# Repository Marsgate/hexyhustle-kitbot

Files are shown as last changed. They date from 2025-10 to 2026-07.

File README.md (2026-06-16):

# Hexy Hustle Kit Bot
This repository contains the CAD, code, and assembly instructions necessary to build a Hexy Hustle Kit Bot.

## Printing
Printable STLs have been provided for all kit bot parts in the STL folder. Check the BOM for quantity to print.

All kits are printed on Bambu Labs 0.20mm Standard settings. 

## Standard Hardware
Kitbots utilize the following standard hardware
- 4mm Round Shafts
- 5mm Hex Shafts
- M3 Socket Head Screws
- M3 Heatset Inserts

When designing 3D printable parts to interface with this hardware, the following dimensions tend to work well.
- 0.13", M3 screw thru hole diameter for hole printed flat
- 0.14", M3 screw thru hole diameter for hold printed standing up
- 0.15", Counterbore depth for M3 socket screws 
- 0.18", M3 Heatset insert hole diameter
- 0.115", M3 hole diameter for threading into the plastic when printed flat
- 0.108", M3 hole diameter for threading into the plastic when printed standing up
- 0.25", 5mm Hex shaft thru hole diameter
- 0.2", Blind depth of a heatset insert hole
- 0.18", 4mm Shaft thru hole diameter

Holes printed standing up are smaller to accounts for drooping during printing. This may vary from printer to printer depending on overhang performance.

## Assembly
If you did not buy a kit that contains all prints, start by printing the STLs contained in CAD/Kitbot. Reference the BOM.md to see quantities of each part to print. If a part is mirrored, a pre-mirrored STL is provided for convenience.

Assembly video coming soon!

## Lipo charging
Do not leave batteries unattended while charging! 
It is reccommended that you charge batteries in a lipo safe bag/box.

B6 Neo manual:
https://www.skyrc.com/download/100198%20B6neo%20Instruction%20Manual%20V1.1_240318.pdf

After using the batteries, it is reccommended to discharge them to storage voltage for longevity.

## Code

### Setup

1. Install the Arduino IDE https://www.arduino.cc/en/software/
2. Add the ESP32 and Bluepad32 board packages to Board Manager
- [Video Tutorial](https://www.youtube.com/watch?v=0jnY-XXiD8Q) (You do not need to open the example project)
- Paste the following text into the "additional boards manager URLs" section per the instructions linked above.
 ```
 https://raw.githubusercontent.com/espressif/arduino-esp32/gh-pages/package_esp32_index.json
 https://raw.githubusercontent.com/ricardoquesada/esp32-arduino-lib-builder/master/bluepad32_files/package_esp32_bluepad32_index.json
 ```
- Install the esp32 and bluepad32 packages by clicking the "Install" button in the board manager.
3. Install the ESP32Servo library
4. Open the Code.ino file
5. Select the board "esp32_bluepad32 > ESP32 Dev Module"
6. Plug in the brain, and select the COM port that appears.
7. Verify that uploading code to the brain works

If the upload fails, try setting the baud rate to 115200 and retrying.

### Configuration

Define all motors and servos at the top of Code.ino
Here are the example definitions from the kitbot itself
```
// motors
Motor leftDrive;
Motor rightDrive;
Motor intake;
Motor hang;

// servos
ServoMotor flipper;
const int flipperMin = 500;
const int flipperMax = 2050;
```
Defining limits for the servo is helpful for writing driver controls. These should be values between 500 and 2500.

In the `setup()` function, assign motor and servo ports. DC motors can be reversed by adding `,1` after the port. Servos should be given a starting position that it moves to when the robot is turned on. This is usually the min or max value, but doesn't have to be.
```
// motors
leftDrive.init(M3); 
rightDrive.init(M4, 1); // reversed
intake.init(M6);
hang.init(M2);

// servos
flipper.init(S1, flipperMin);
```

### Driver Controls

In the `driverControls()` function, map controller buttons to subsystems
```
// intake
if (ctl->r1()) {
    intake.move(100);
} else if (ctl->r2()) {
    intake.move(-100);
} else {
    intake.move(0);
}
```
In this example, the intake runs forward when R1 is pressed, backwards when R2 is pressed, and stops when neither button is pressed.

For the chassis controls, they are configured for split arcade by default.
```
leftDrive.move(y-x);
rightDrive.move(y+x);
```

#### Split Arcard
Get the joystick values from the same stick, instead of two different sticks.
```
// left stick
int x = ctl->axisX();
int y = ctl->axisY();
```
```
// right stick
int x = ctl->axisRX();
int y = ctl->axisRY();
```

#### Tank Drive
Switch from the RX axis to the RY axis.
```
// get joysticks
int x = ctl->axisRY();
int y = ctl->axisY();
```
Then update the left and right drive assignment to use the joystick values directly instead of adding/subtracting them.
```
leftDrive.move(y);
rightDrive.move(x);
```

## Attribution
Credit to Ricardo Quesada for creating the bluepad32 library that the Kitbot runs on
https://github.com/ricardoquesada/bluepad32

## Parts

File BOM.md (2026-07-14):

# BOM

## Items included in the kit

### Electronics
- The Flight Controller x1
- [XT60-XT30 Short Cable x1](https://a.co/d/0g4YD8ml)
- [XT60-XT30 Long Cable x1](https://a.co/d/04mg2y1r)
- [B6 Neo Lipo Charger x1](https://a.co/d/05w2RGuz)
- [3S Lipo x1](https://a.co/d/0hQ7UNYJ)
- [DC Motor w/ Motor cap x4](https://www.aliexpress.us/item/3256807353631389.html)
- [Servo Motor x1](https://a.co/d/05sNs3aC)
- [Extension Cables x2](https://a.co/d/09EsJgbW)

### Hardware
- [Heatset insert pack x1](https://a.co/d/0esVJgH2)
- [Screw pack x1](https://a.co/d/09cQsdQA)
- [Allen wrench x1](https://a.co/d/01DbpG43)
- [Nylon string x1](https://a.co/d/0iqGt5RV)
- [Round Shafts x6](https://a.co/d/01yORJ63)
- [Hex Shafts x3](https://a.co/d/0f2OXTUU)
- [Rubber tubing x1](https://a.co/d/09hxUCcK)
- [Ziptie Pack x1](https://a.co/d/0elJUc7y)
- [Rubber Band Pack x1](https://a.co/d/08hcKJ02)
- [Traction Wheel x2](https://banebots.com/t61p-243bg/)
- [Flex Wheel x 4](https://banebots.com/t61p-203bg/)

### Prints
- 12T Hex Gear x1
- 12T M3 Gear x3 
- 19T D Gear x2
- 24T D Gear x2
- 24T Hex Gear x1
- 24T M3 Gear x2
- 36T Hex Gear x1
- 42T Wheel Insert x2
- 48T M3 Gear x1
- Battery Holder x1
- Chassis x1
- Flexwheel Insert x4
- Flipper Arm x1
- Flipper Linkage x1
- Flipper Motor Cap x1
- Flipper Motor Mount x1
- Flipper Paddle Mount x2 Mirrored
- Flipper Paddle x1
- Hang Arm x2 Mirrored
- Hang Crossbrace
- Hex Collar x1
- Intake Arm x2 Mirrored
- Intake Tower x2 Mirrored
- Intake Brace x1
- Omni Wheel x4
    - Omni Roller x16
    - Omni Bottom x2
    - Omni Top x2
    - Omni Spacer x1
    - Omni Post x1
    - Omni Cap x1
- Rear Tower x2 Mirrored
- Tower Brace x2 Mirrored
- Tower Standoff x1

## Items that are required, but are not included
- [USB-C PD3.0/QC Charging block for the lipo charger (Most tablet/laptop chargers will work)](https://a.co/d/05AJ3r7P)
- [USB-C cable for the lipo charger and programming the brain](https://a.co/d/07pgoZjv)
- [Bluetooth controller (PS4/5, Xbox, etc)](https://a.co/d/0fHtbTdB)

## Items Required to build your own flight controller
- PCB (gerbers and schematics in CAD/electronics/kitbot_brain)
- [10kOhm SMD 1206 resistors x4](https://a.co/d/0fsyfGzN)
- [1uF SMD 1206 capacitor x1](https://a.co/d/06gvHcsD)
- [JST XH 2.54mm 2 pin male right angle connector x6](https://a.co/d/0iDRtF4O)
- [JST XH 2.54mm 4 pin male right angle connector x1](https://a.co/d/0iDRtF4O)
- [Right angle 2.54mm male pin header](https://a.co/d/06wsUiik)
- [2.54mm female pin header](https://a.co/d/0bTpzli6)
- [XT60 PCB mount connector](https://a.co/d/0bN5OuDN)
- [ESP32 WROOM dev board](https://a.co/d/0duQxi1H)
- [DRV8833 H-bridge board x3](https://a.co/d/0iz36L0V)
- [Adjustable buck converter](https://a.co/d/0euiQGr1)

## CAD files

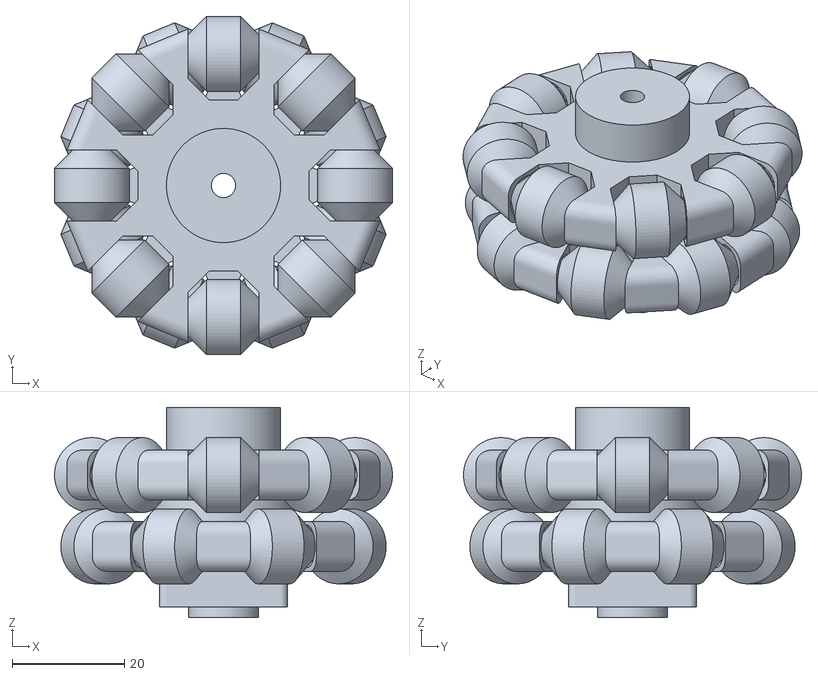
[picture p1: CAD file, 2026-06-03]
CAD/Kitbot/Omni Wheel/Full Omni.stl
60.2 x 60.2 x 37.5

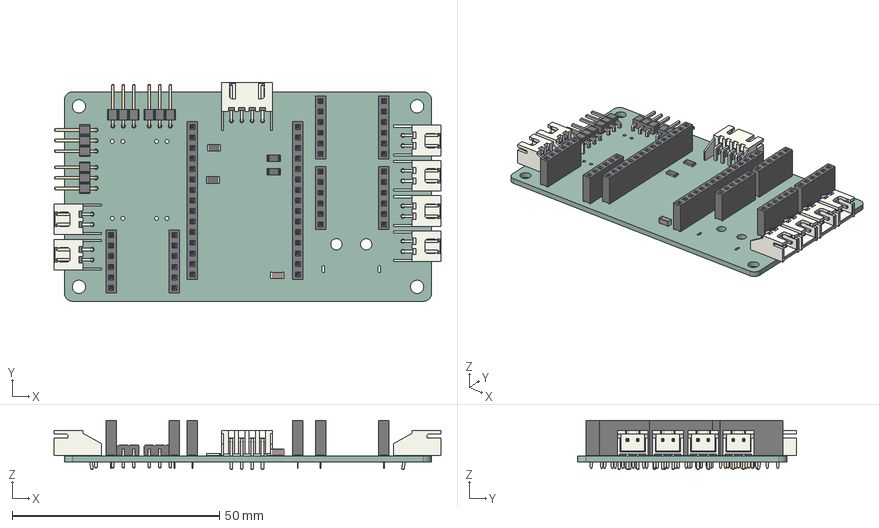
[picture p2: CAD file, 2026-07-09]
CAD/Electronics/kitbot_brain/kitbot_brain.step
93.3 x 52.7 x 11.9 mm
PinHeader_1x03_P2.54mm_Horizontal x 4
C_1206_3216Metric
R_1206_3216Metric x 4
JST_XH_S2B-XH-A_1x02_P2.50mm_Horizontal x 6
PinSocket_1x06_P2.54mm_Vertical x 6
PinSocket_1x15_P2.54mm_Vertical x 2
JST_XH_S4B-XH-A_1x04_P2.50mm_Horizontal
PBB_PCB

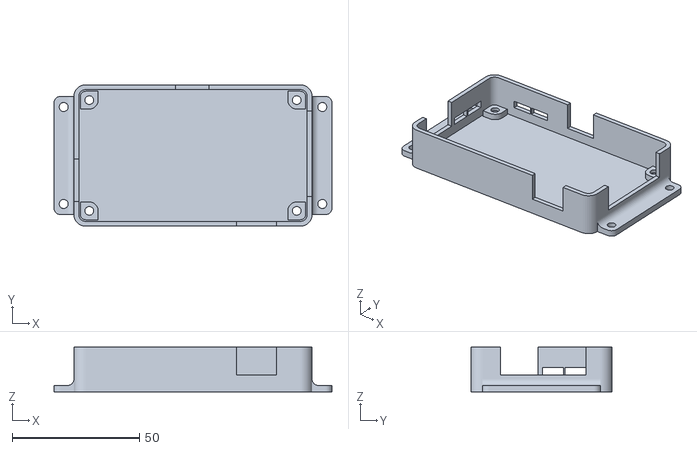
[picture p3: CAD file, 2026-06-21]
CAD/Electronics/STL/case bottom.stl
109.2 x 55.6 x 17.7

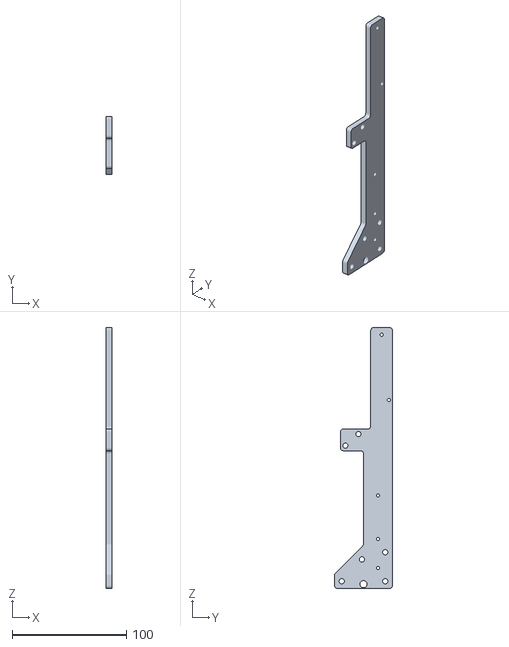
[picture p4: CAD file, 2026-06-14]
CAD/Kitbot/Intake Tower(Mirror).stl
5.08 x 50.8 x 228.6

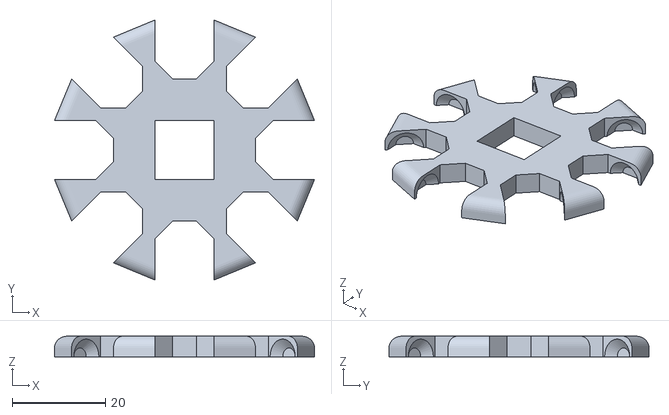
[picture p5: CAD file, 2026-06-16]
CAD/Kitbot/Omni Wheel/Omni Bottom.stl
55.7 x 55.7 x 4.44

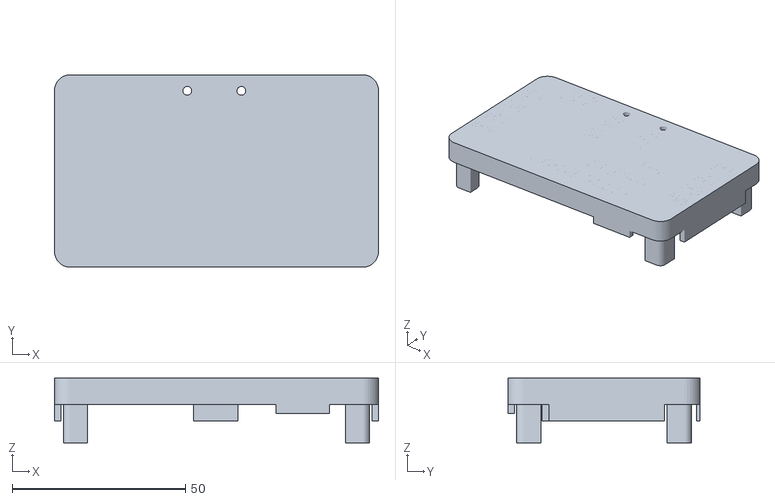
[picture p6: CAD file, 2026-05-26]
CAD/Electronics/STL/case top.stl
93.6 x 55.6 x 18.7

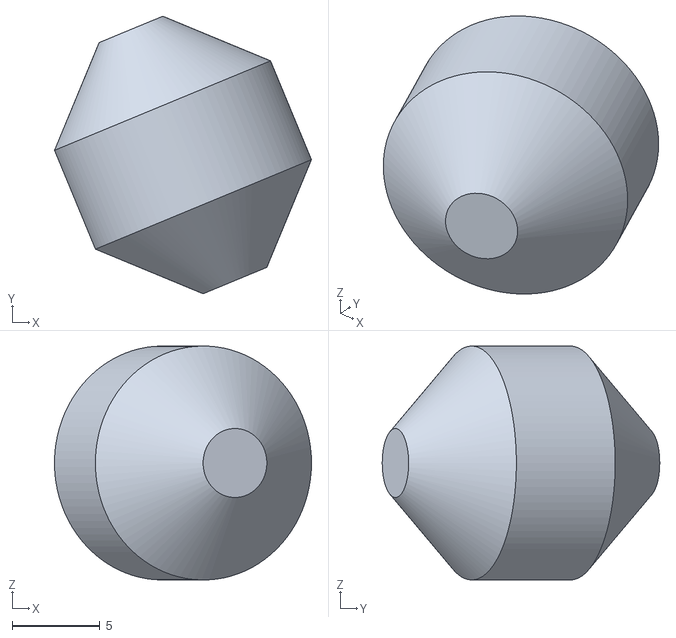
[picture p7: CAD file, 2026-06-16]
CAD/Kitbot/Omni Wheel/Omni Roller.stl
14.6 x 15.8 x 13.3

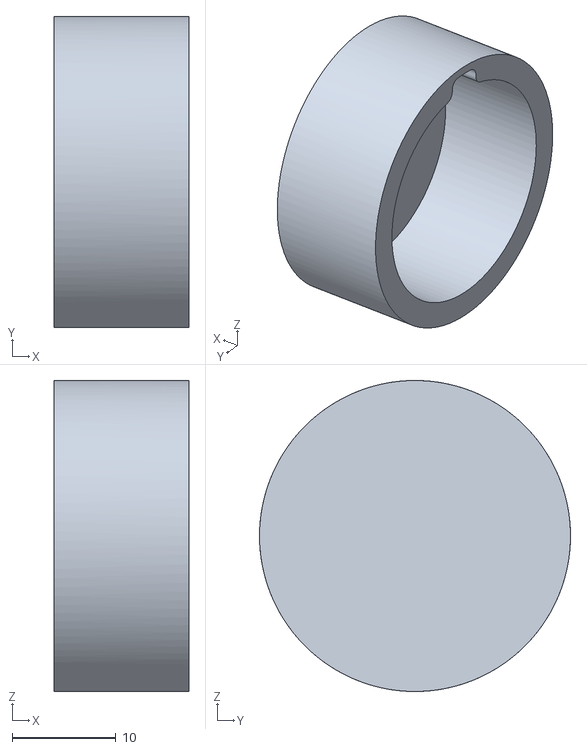
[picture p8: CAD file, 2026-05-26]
CAD/Electronics/STL/Motor Cap.stl
13.0 x 30.0 x 30.0

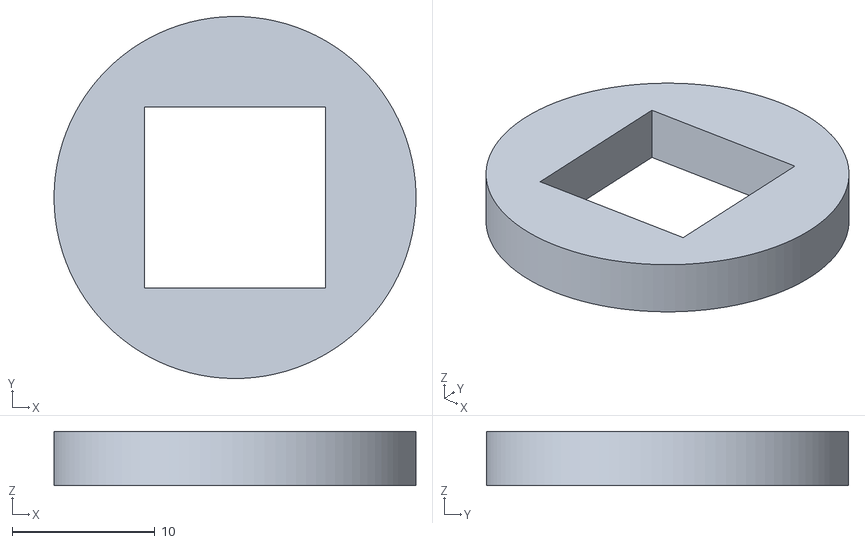
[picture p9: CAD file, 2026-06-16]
CAD/Kitbot/Omni Wheel/Omni Spacer.stl
25.4 x 25.4 x 3.81

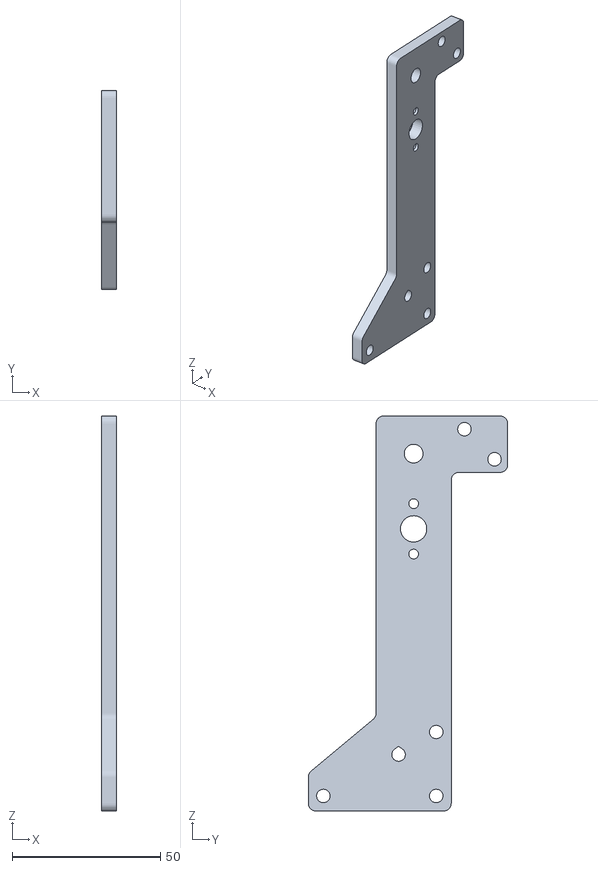
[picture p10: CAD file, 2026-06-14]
CAD/Kitbot/Rear Tower.stl
5.08 x 67.3 x 133.3

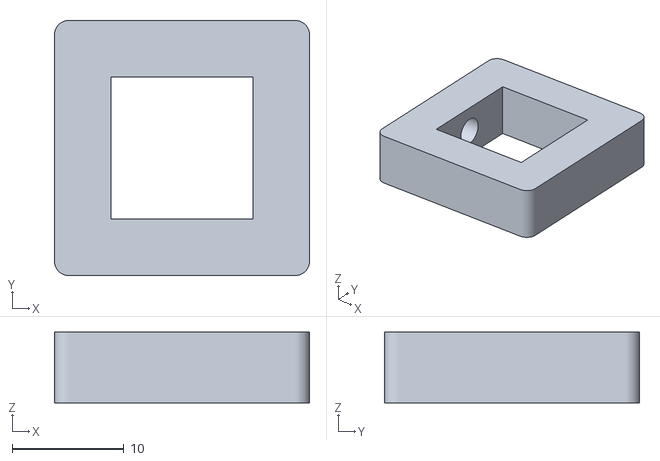
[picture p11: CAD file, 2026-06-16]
CAD/Kitbot/Omni Wheel/Omni Cap.stl
22.9 x 22.9 x 6.35

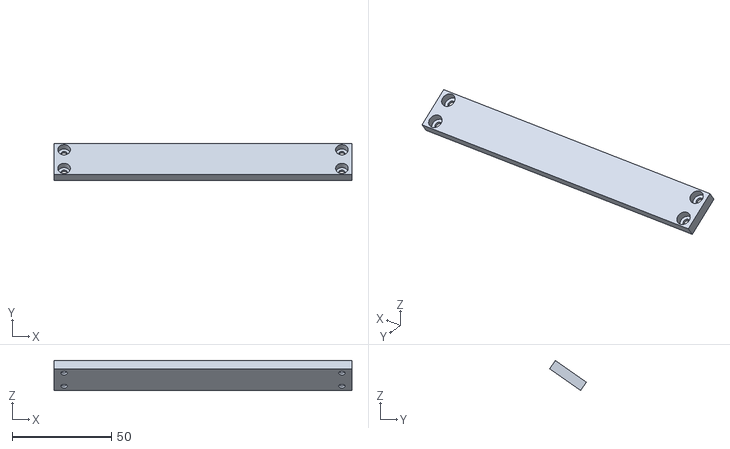
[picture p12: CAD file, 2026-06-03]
CAD/Kitbot/Intrake Brace.stl
149.9 x 18.5 x 15.1

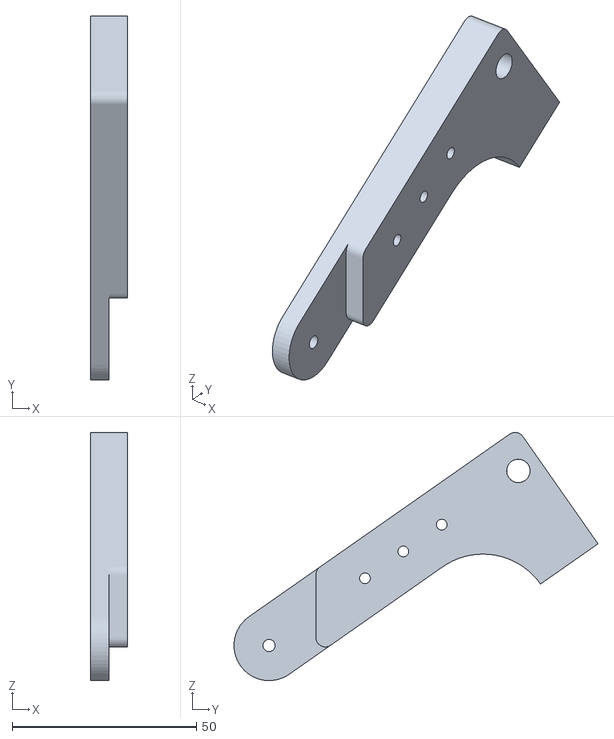
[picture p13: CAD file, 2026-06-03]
CAD/Kitbot/Intake Arm(Mirror).stl
10.2 x 98.7 x 67.3

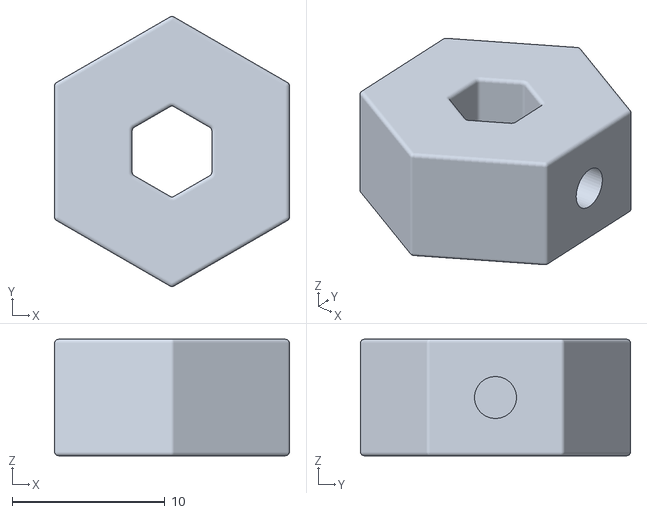
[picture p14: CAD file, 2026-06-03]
CAD/Kitbot/Hex Collar.stl
15.4 x 17.7 x 7.62

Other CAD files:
CAD/Kitbot/Intake Tower.stl
CAD/Kitbot/Rear Tower(Mirror).stl
CAD/Kitbot/Omni Wheel/Omni Top.stl
CAD/Kitbot/Intake Arm.stl
CAD/Kitbot/12T Hex Gear.stl
CAD/Kitbot/12T M3 Gear.stl
CAD/Kitbot/19T D Gear.stl
CAD/Kitbot/24T D Gear.stl
CAD/Kitbot/24T Hex Gear.stl
CAD/Kitbot/24T m3 gear.stl
CAD/Kitbot/36T Hex Gear.stl
CAD/Kitbot/42T Wheel Insert.stl
CAD/Kitbot/48T m3 gear.stl
CAD/Kitbot/Battery Holder.stl
CAD/Kitbot/Chassis.stl
CAD/Kitbot/Flexwheel Insert.stl
CAD/Kitbot/Flipper Arm.stl
CAD/Kitbot/Flipper Linkage.stl
CAD/Kitbot/Flipper Motor Cap.stl
CAD/Kitbot/Flipper Motor Mount.stl
CAD/Kitbot/Flipper Paddle Mount(Mirror).stl
CAD/Kitbot/Flipper Paddle Mount.stl
CAD/Kitbot/Flipper Paddle.stl
CAD/Kitbot/Hang Arm(Mirror).stl
CAD/Kitbot/Hang Arm.stl
CAD/Kitbot/Hang Crossbrace.stl
CAD/Kitbot/Omni Wheel/Omni Bolt.stl
CAD/Kitbot/Tower Brace(Mirror).stl
CAD/Kitbot/Tower Brace.stl
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

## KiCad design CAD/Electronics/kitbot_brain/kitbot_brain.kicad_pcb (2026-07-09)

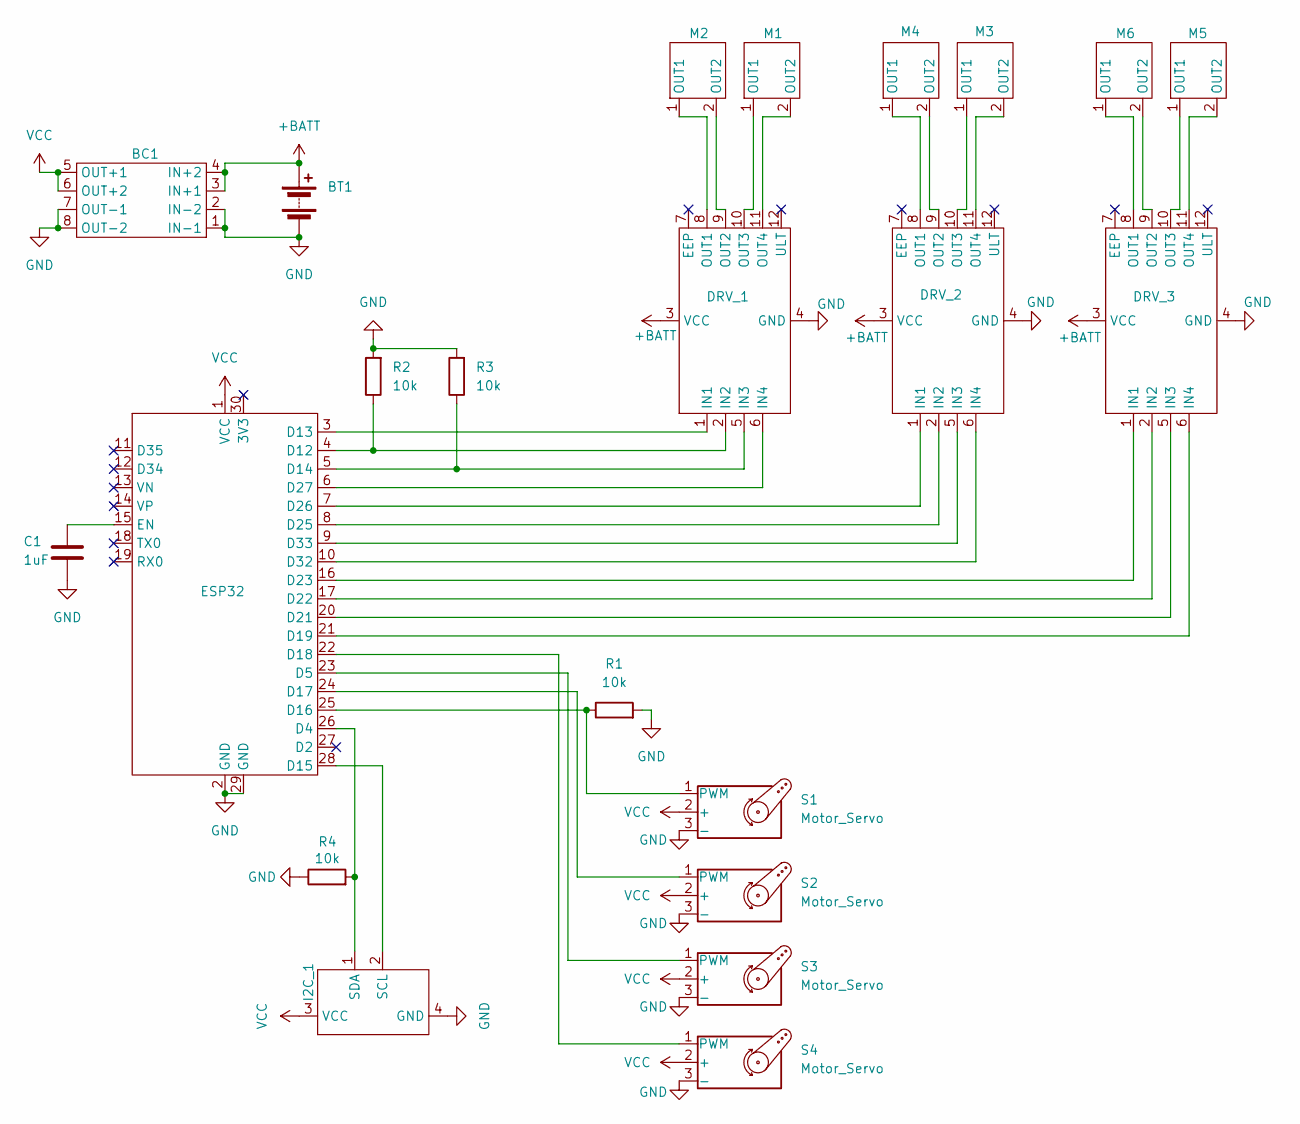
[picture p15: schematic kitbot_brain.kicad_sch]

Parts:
BC1: buck converter
BT1: Battery; AMASS_XT60PW-M_1x02_P7.20mm_Horizontal
C1: 1uF; C_1206_3216Metric_Pad1.33x1.80mm_HandSolder
DRV_1, DRV_2, DRV_3: drv8833
ESP32: ESP32
I2C_1: JST_XH_S4B-XH-A_1x04_P2.50mm_Horizontal
M1, M2, M3, M4, M5, M6: JST_XH_S2B-XH-A_1x02_P2.50mm_Horizontal
R1, R2, R3, R4: 10k; R_1206_3216Metric_Pad1.30x1.75mm_HandSolder
S1, S2, S3, S4: Motor_Servo; PinHeader_1x03_P2.54mm_Horizontal

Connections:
+BATT: BC1.3 (IN+1), BC1.4 (IN+2), BT1.1 (+), DRV_1.3 (VCC), DRV_2.3 (VCC), DRV_3.3 (VCC)
GND: BC1.1 (IN-1), BC1.2 (IN-2), BC1.7 (OUT-1), BC1.8 (OUT-2), BT1.2 (-), C1.2, DRV_1.4 (GND), DRV_2.4 (GND), DRV_3.4 (GND), ESP32.2 (GND), ESP32.29 (GND), I2C_1.4 (GND), R1.2, R2.2, R3.2, R4.1, S1.3 (-), S2.3 (-), S3.3 (-), S4.3 (-)
unnamed: DRV_1.1 (IN1), ESP32.3 (D13)
unnamed: DRV_1.2 (IN2), ESP32.4 (D12), R2.1
unnamed: DRV_1.5 (IN3), ESP32.5 (D14), R3.1
unnamed: DRV_1.6 (IN4), ESP32.6 (D27)
unnamed: DRV_1.8 (OUT1), M2.1 (OUT1)
unnamed: DRV_1.9 (OUT2), M2.2 (OUT2)
unnamed: DRV_1.10 (OUT3), M1.1 (OUT1)
unnamed: DRV_1.11 (OUT4), M1.2 (OUT2)
unnamed: DRV_2.1 (IN1), ESP32.7 (D26)
unnamed: DRV_2.2 (IN2), ESP32.8 (D25)
unnamed: DRV_2.5 (IN3), ESP32.9 (D33)
unnamed: DRV_2.6 (IN4), ESP32.10 (D32)
unnamed: DRV_2.8 (OUT1), M4.1 (OUT1)
unnamed: DRV_2.9 (OUT2), M4.2 (OUT2)
unnamed: DRV_2.10 (OUT3), M3.1 (OUT1)
unnamed: DRV_2.11 (OUT4), M3.2 (OUT2)
unnamed: DRV_3.1 (IN1), ESP32.16 (D23)
unnamed: DRV_3.2 (IN2), ESP32.17 (D22)
unnamed: DRV_3.5 (IN3), ESP32.20 (D21)
unnamed: DRV_3.6 (IN4), ESP32.21 (D19)
unnamed: DRV_3.8 (OUT1), M6.1 (OUT1)
unnamed: DRV_3.9 (OUT2), M6.2 (OUT2)
unnamed: DRV_3.10 (OUT3), M5.1 (OUT1)
unnamed: DRV_3.11 (OUT4), M5.2 (OUT2)
unnamed: ESP32.26 (D4), I2C_1.1 (SDA), R4.2
unnamed: ESP32.23 (D5), S3.1 (PWM)
unnamed: ESP32.28 (D15), I2C_1.2 (SCL)
unnamed: ESP32.25 (D16), R1.1, S1.1 (PWM)
unnamed: ESP32.24 (D17), S2.1 (PWM)
unnamed: ESP32.22 (D18), S4.1 (PWM)
unnamed: C1.1, ESP32.15 (EN)
VCC: BC1.5 (OUT+1), BC1.6 (OUT+2), ESP32.1 (VCC), I2C_1.3 (VCC), S1.2 (+), S2.2 (+), S3.2 (+), S4.2 (+)

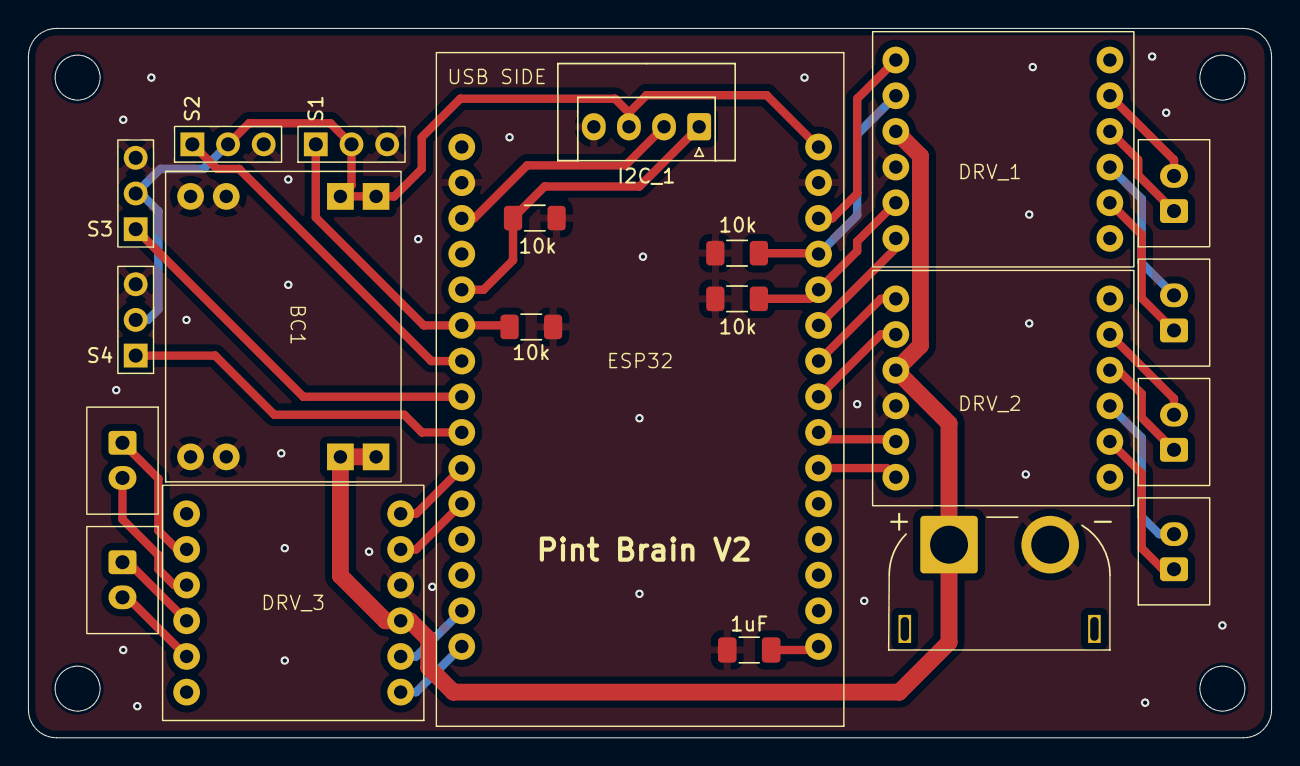
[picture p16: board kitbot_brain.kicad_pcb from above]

Board: 2 copper layers, 88.5 x 50.5 mm, 22 parts (0 on the bottom side), 34 nets.

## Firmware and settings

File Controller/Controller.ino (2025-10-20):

#include <Bluepad32.h>
#include <ESP32Servo.h>
#include <Preferences.h>

int leftDrivePin = 13;
int rightDrivePin = 14;
int liftPin = 34;
int intakePin = 27;
int winchPin = 26;

Servo leftDrive;
Servo rightDrive;
Servo lift;
Servo intake;
Servo winch;

int liftPosition = 1500;
const int liftUpperBound = 2300;
const int liftLowerBound = 650;

ControllerPtr myControllers[BP32_MAX_GAMEPADS];

Preferences preferences;

// This callback gets called any time a new gamepad is connected.
// Up to 4 gamepads can be connected at the same time.
void onConnectedController(ControllerPtr ctl) {
    bool foundEmptySlot = false;
    for (int i = 0; i < BP32_MAX_GAMEPADS; i++) {
        if (myControllers[i] == nullptr) {
            Serial.printf("CALLBACK: Controller is connected, index=%d\n", i);
            // Additionally, you can get certain gamepad properties like:
            // Model, VID, PID, BTAddr, flags, etc.
            ControllerProperties properties = ctl->getProperties();
            Serial.printf("Controller model: %s, VID=0x%04x, PID=0x%04x\n", ctl->getModelName().c_str(), properties.vendor_id,
                           properties.product_id);
            myControllers[i] = ctl;
            foundEmptySlot = true;
            break;
        }
    }
    if (!foundEmptySlot) {
        Serial.println("CALLBACK: Controller connected, but could not found empty slot");
    }
    digitalWrite(2, LOW);
}

void onDisconnectedController(ControllerPtr ctl) {
    bool foundController = false;

    for (int i = 0; i < BP32_MAX_GAMEPADS; i++) {
        if (myControllers[i] == ctl) {
            Serial.printf("CALLBACK: Controller disconnected from index=%d\n", i);
            myControllers[i] = nullptr;
            foundController = true;
            break;
        }
    }

    if (!foundController) {
        Serial.println("CALLBACK: Controller disconnected, but not found in myControllers");
    }

    digitalWrite(2, HIGH);
}

void dumpGamepad(ControllerPtr ctl) {
    Serial.printf(
        "idx=%d, dpad: 0x%02x, buttons: 0x%04x, axis L: %4d, %4d, axis R: %4d, %4d, brake: %4d, throttle: %4d, "
        "misc: 0x%02x, gyro x:%6d y:%6d z:%6d, accel x:%6d y:%6d z:%6d\n",
        ctl->index(),        // Controller Index
        ctl->dpad(),         // D-pad
        ctl->buttons(),      // bitmask of pressed buttons
        ctl->axisX(),        // (-511 - 512) left X Axis
        ctl->axisY(),        // (-511 - 512) left Y axis
        ctl->axisRX(),       // (-511 - 512) right X axis
        ctl->axisRY(),       // (-511 - 512) right Y axis
        ctl->brake(),        // (0 - 1023): brake button
        ctl->throttle(),     // (0 - 1023): throttle (AKA gas) button
        ctl->miscButtons(),  // bitmask of pressed "misc" buttons
        ctl->gyroX(),        // Gyro X
        ctl->gyroY(),        // Gyro Y
        ctl->gyroZ(),        // Gyro Z
        ctl->accelX(),       // Accelerometer X
        ctl->accelY(),       // Accelerometer Y
        ctl->accelZ()        // Accelerometer Z
    );
}

void processGamepad(ControllerPtr ctl) {
    if (ctl->a()) {
        static int colorIdx = 0;
        // Some gamepads like DS4 and DualSense support changing the color LED.
        // It is possible to change it by calling:
        switch (colorIdx % 3) {
            case 0:
                // Red
                ctl->setColorLED(255, 0, 0);
                break;
            case 1:
                // Green
                ctl->setColorLED(0, 255, 0);
                break;
            case 2:
                // Blue
                ctl->setColorLED(0, 0, 255);
                break;
        }
        colorIdx++;
    }

    // winch
    if (ctl->x()) {
        winch.write(180);
    } else if (ctl->y()) {
        winch.write(0);
    } else {
        winch.write(90);
    }

    // intake
    if (ctl->r1()) {
        intake.write(180);
    } else if (ctl->r2()) {
        intake.write(0);
    } else {
        intake.write(90);
    }

    // lift
    if (ctl->l1()) {
        liftPosition += 20;
    } else if (ctl->l2()) {
        liftPosition -= 20;
    }

    if (liftPosition > liftUpperBound) {
        liftPosition = liftUpperBound;
    } else if (liftPosition < liftLowerBound) {
        liftPosition = liftLowerBound;
    }

    lift.writeMicroseconds(liftPosition);
  
    // drive
    int x = ctl->axisRX();
    int y = ctl->axisY();

    if (abs(x) < 100) {
        x = 0;
    }
    if (abs(y) < 100) {
        y = 0;
    }

    x = map(x, 512, -512, -90, 90);
    y = map(y, 512, -512, 0, 180);

    Serial.print("X:");
    Serial.print(x);
    Serial.print("    Y:");
    Serial.println(y);
    
    // Serial.println(liftPosition);

    leftDrive.write(y-x);
    rightDrive.write(map((y+x), 180, 0, 0, 180));
    

    // Another way to query controller data is by getting the buttons() function.
    // See how the different "dump*" functions dump the Controller info.
    // dumpGamepad(ctl);
}

void processControllers() {
    for (auto myController : myControllers) {
        if (myController && myController->isConnected() && myController->hasData()) {
            if (myController->isGamepad()) {
                processGamepad(myController);
            } else {
                Serial.println("Unsupported controller");
            }
        }
    }
}

// Arduino setup function. Runs in CPU 1
void setup() {
    pinMode(2, OUTPUT);

    pinMode(leftDrivePin, OUTPUT);
    leftDrive.attach(leftDrivePin, 1000, 2000);
    leftDrive.attach(leftDrivePin, 1000, 2000);

    pinMode(rightDrivePin, OUTPUT);
    rightDrive.attach(rightDrivePin, 1000, 2000);
    rightDrive.attach(rightDrivePin, 1000, 2000);

    pinMode(liftPin, OUTPUT);
    lift.attach(liftPin, liftLowerBound, liftUpperBound);
    lift.attach(liftPin, liftLowerBound, liftUpperBound);

    pinMode(intakePin, OUTPUT);
    intake.attach(intakePin, 1000, 2000);
    intake.attach(intakePin, 1000, 2000);

    pinMode(winchPin, OUTPUT);
    winch.attach(winchPin, 1000, 2000);
    winch.attach(winchPin, 1000, 2000);


    Serial.begin(115200);
    Serial.printf("Firmware: %s\n", BP32.firmwareVersion());
    const uint8_t* addr = BP32.localBdAddress();
    Serial.printf("BD Addr: %2X:%2X:%2X:%2X:%2X:%2X\n", addr[0], addr[1], addr[2], addr[3], addr[4], addr[5]);

    // Setup the Bluepad32 callbacks
    BP32.setup(&onConnectedController, &onDisconnectedController);

    BP32.enableBLEService(false); // set to true if using a BLE controller (xbox)

    // check for paired controller
    preferences.begin("robot", false);
    if (preferences.getBool("paired") == true) {
        Serial.println ("Controller already paired");
        BP32.enableNewBluetoothConnections(false); // do not allow new connections if there is a paired controller
    } else {
        Serial.println ("No paired controller");

        // forget previous controllers and connect to a new controller
        BP32.forgetBluetoothKeys();
        BP32.enableNewBluetoothConnections(true);
        preferences.putBool("paired", true); // assume a controller was paired
        digitalWrite(2, HIGH); // turn on the LED to let the user know we are in pairing mode
    }
    preferences.end();
}

// Arduino loop function. Runs in CPU 1.
void loop() {

    // This call fetches all the controllers' data.
    // Call this function in your main loop.
    bool dataUpdated = BP32.update();
    if (dataUpdated)
        processControllers();

    // if the boot button is pressed, send the board into pairing mode
    if (digitalRead(0) == LOW) {
        Serial.println("Entering pairing mode on next reboot");
        preferences.begin("robot", false);
        preferences.putBool("paired", false); // set robot to unpair at next reboot
        preferences.end();

        digitalWrite(2, HIGH); // turn on the LED to let the user know we are in pairing mode
        
        while (digitalRead(0) == LOW) vTaskDelay(10);
        esp_restart();
    }

    //     vTaskDelay(1);
    vTaskDelay(10);
}

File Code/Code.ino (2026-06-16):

#include "psr.h"

ControllerPtr ctl;

// motors
Motor leftDrive;
Motor rightDrive;
Motor intake;
Motor hang;

// servos
ServoMotor flipper;
const int flipperMin = 500;
const int flipperMax = 2050;

void driverControls() {
    // hang
    if (ctl->l2()) {
        hang.move(100);
    } else if (ctl->y()) {
        hang.move(-100);
    } else {
        hang.move(0);
    }

    // intake
    if (ctl->r1()) {
        intake.move(100);
    } else if (ctl->r2()) {
        intake.move(-100);
    } else {
        intake.move(0);
    }

    // flipper
    if (ctl->l1()) {
        flipper.moveAbsolute(flipperMax);
    } else {
        flipper.moveAbsolute(flipperMin);
    }
  
    // get joysticks
    int x = ctl->axisRX();
    int y = ctl->axisY();

    // deadzone
    if (abs(x) < 100) {
        x = 0;
    }
    if (abs(y) < 100) {
        y = 0;
    }

    // limits
    if (x > 512) {
        x = 512;
    } else if (x < -512) {
        x = -512;
    }

    if (y > 512) {
        y = 512;
    } else if (y < -512) {
        y = -512;
    }

    // map to +/- 100
    x = map(x, 512, -512, 100, -100);
    y = map(y, 512, -512, 100, -100);

    leftDrive.move(y-x);
    rightDrive.move(y+x);
}

// Arduino setup function. Runs in CPU 1
void setup() {
    Serial.begin(115200);

    psrInit();
    BP32.enableBLEService(true); // set to true for BLE controllers (xbox)

    // motors
    leftDrive.init(M3);
    rightDrive.init(M4, 1); // reversed
    intake.init(M6);
    hang.init(M2);

    // servos
    flipper.init(S1, flipperMin);
}

void loop() {
    
    delay(1); // the loop requires a delay

    // if the boot button is pressed, send the board into pairing mode
    if (digitalRead(BOOT_BTN) == LOW) {
        enterPairingMode();
    }

    // get bluetooth data from the controller
    bool dataUpdated = BP32.update();
    if (!dataUpdated || !ctl || !ctl->isConnected() || !ctl->hasData()) {
        return; // if no controller is connected and returning data, skip the driver controls
    }

    // dumpGamepad(ctl); // uncomment to print controller inputs to the serial monitor

    driverControls();
}

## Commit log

2025-09-20 Add STLs for emergency reprints
    [12t motor gear.stl, goater mount.stl, intake motor mount.stl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]
2025-10-20 Turn on the onboard LED on disconnect
2025-10-20 Use boot button to put board into pairing mode
2025-10-31 Fix ESC initialization beeping
    [pbr.cpp]
2026-05-26 Add STLs
    [12T Hex Gear.stl, 12T M3 Gear.stl, 12t motor gear.stl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]
2026-05-26 Update readme and reorganize project
    [12T Hex Gear.stl, 12T M3 Gear.stl, 19T D Gear.step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]
2026-05-26 Update BOM
2026-05-26 Update traction wheel STL
    [42T Wheel Insert.stl]
2026-05-28 Fix Intake tower motor mount holes
    [Intake Tower(Mirror).stl]
2026-05-29 Fix m3 hole tolerance
    [24T D Gear.stl, Tower Standoff.stl]
2026-06-03 Updates after building Nathan's bot
    [19T D Gear.stl, 24T D Gear.stl, 24T Hex Gear.stl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]
2026-06-03 More updates based on build feedback
    [Intake Arm(Mirror).stl, Intake Arm.stl, Intrake Brace.stl]
2026-06-03 Add full bot plate
2026-06-14 Update tower STLs
    [Intake Tower(Mirror).stl, Intake Tower.stl, Rear Tower(Mirror).stl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]
2026-06-14 Add extension cables to BOM
2026-06-16 Add links to BOM
2026-06-16 Add individual omni STLs
    [Full Omni.stl, Omni Bolt.stl, Omni Bottom.stl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]
2026-06-21 Increase case counterbore
    [case bottom.stl]
2026-07-09 Add kicad files
    [Motor Cap.stl, case bottom.stl, case top.stl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]
